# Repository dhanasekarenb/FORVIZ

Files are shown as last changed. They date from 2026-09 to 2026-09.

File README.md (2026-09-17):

# FORVIZ — face-tracking robot

FORVIZ is a stationary Raspberry Pi robot with a pan/tilt head, a camera, and one or two animated OLED displays. YuNet detects faces, the controller follows the largest face, and the eyes become happy after it stays centered for one second.

The V3 enclosure is a modular design intended for **PLA printing with a 0.4 mm nozzle**, using removable printed retainers and mechanically captive stock servo horns. No glue or added assembly screws are intended. **V3 is an engineering prototype; physical fit and loaded operation have not yet been tested.** Print the fit coupons and follow the mechanical guide before printing and assembling everything.

- [V3 mechanical and printing guide](docs/MECHANICAL_V3.md)
- [V3 printable STL files](3d_models/v3/stl)
- [Interactive 3D preview](docs/robot_preview.html) — download/open locally; works offline
- [Runtime, calibration, and troubleshooting](docs/RUNTIME.md)

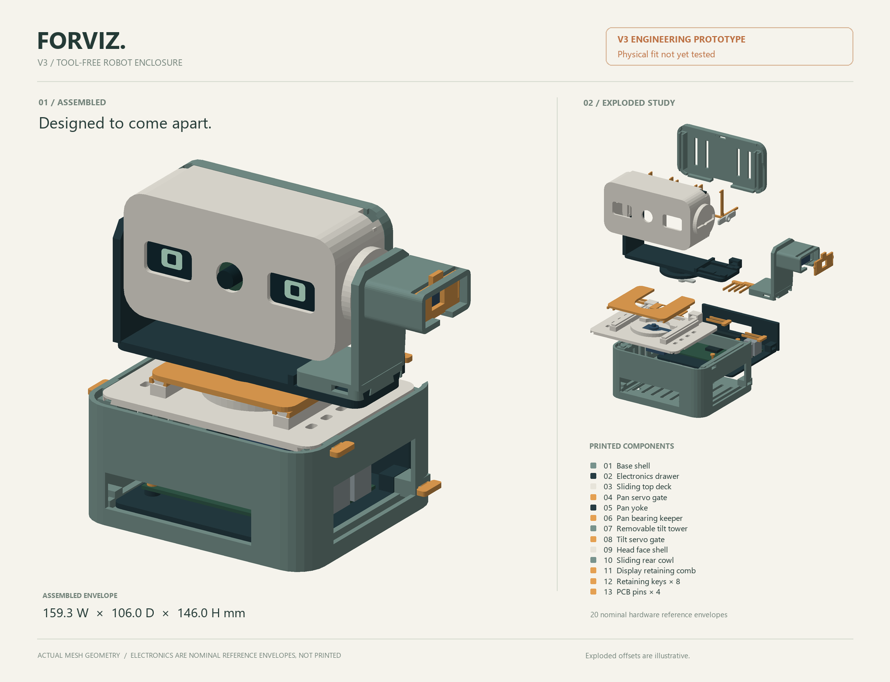
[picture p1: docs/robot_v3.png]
V3 engineering prototype: assembled and exploded printed components, physical fit not yet tested


## Hardware

| Component | Quantity | Purpose |
| --- | --- | --- |
| Raspberry Pi 4 Model B | 1 | Camera capture and face detection |
| Raspberry Pi Camera Rev 1.3 | 1 | CSI camera input |
| SG90 positional micro servo, with stock horn | 2 | Pan and tilt |
| 0.96-inch 128×64 SSD1306 I2C OLED | 2 for V3 | One eye per display; software also supports one display |
| Regulated external 5 V servo supply | 1 | Servo power, with ground shared with the Pi |
| Raspberry Pi power supply, wiring, and CSI ribbon | As needed | Controller power and interconnections |

Check your actual PCB, servo, and horn dimensions against the [mechanical guide](docs/MECHANICAL_V3.md). Modules sold under the same name can have different outlines. Use the specified stock horns in the printed captive mechanism; do not add horn-retaining screws or modify the servo internals.

## Wiring

Disconnect power before changing wiring. Power the servos from the external regulated 5 V supply and the Pi from its own suitable supply. Join the external supply ground to Pi ground; do not join the two supplies' positive outputs. Wire colors vary, so check the component labels.

| Connection | Destination |
| --- | --- |
| Pan servo signal | BCM GPIO 12, physical pin 32 |
| Tilt servo signal | BCM GPIO 19, physical pin 35 |
| Both servo positive leads | External regulated 5 V |
| Both servo grounds | External supply ground and Pi GND, e.g. physical pin 34 |
| Camera ribbon | Pi CSI camera connector |

For independent left/right eyes, use separate buses for two OLEDs with the same `0x3C` address:

| OLED connection | Left display / bus 1 | Right display / bus 3 |
| --- | --- | --- |
| VCC | 3.3 V, physical pin 1 | 3.3 V, physical pin 17 |
| GND | Physical pin 9 | Physical pin 25 |
| SDA | BCM GPIO 2, physical pin 3 | BCM GPIO 23, physical pin 16 |
| SCL | BCM GPIO 3, physical pin 5 | BCM GPIO 24, physical pin 18 |

The optional bus-3 setup below enables the second display. A display already configured for `0x3D` can instead share bus 1 with a `0x3C` display. The software probes supported addresses automatically. If both OLEDs share bus 1 and address `0x3C`, use `python3 test_oled.py --mirror-eye` and `python3 pi_tracker.py --mirror-eye`: both show the same centered eye. An I2C scan reports one address in that wiring and cannot count the physical screens.

## Set up the Raspberry Pi

Copy the complete project to the Pi and run these commands from its directory:

```bash
bash setup_pi.sh
```

The script installs system packages, enables I2C, attempts to start `pigpiod`, and downloads the YuNet model if it is missing. Check its output: some optional installation and service failures are reported without stopping the script. Keep `pi_tracker.py`, `servos.py`, and `oled_face.py` together. The main program imports the shared controllers.

For the second OLED on GPIO 23/24:

```bash
bash enable_dual_oled.sh
python3 test_oled.py --scan
```

Reboot if bus 3 is not available after enabling it. See [runtime setup troubleshooting](docs/RUNTIME.md#setup-and-dependencies) for dependency versions and `pigpiod` checks.

## Lower processing load and temperature

The tracker requests 320 × 240 capture at 15 FPS, limits detection to 15 runs per second, and uses one OpenCV worker thread. It also caps the inference image's longest side at 320 pixels if a camera returns larger frames. Face coordinates are mapped back to the original frame for tracking.

For the robot's same-bus mirrored OLEDs, run without the camera preview:

```bash
python3 pi_tracker.py --mirror-eye --headless
```

For a lower frame rate:

```bash
python3 pi_tracker.py --mirror-eye --headless --camera-fps 10 --detect-fps 10
```

Keep your existing rotation, servo direction, and calibration flags on these commands. The terminal reports available CPU temperature and firmware throttling flags every ten seconds. Reduced resolution can miss smaller or more distant faces; these defaults have not been thermally measured on your Pi. See [temperature checks and tuning](docs/RUNTIME.md#processing-load-and-temperature).

## Calibrate before tracking

1. **Simulate the servo sequence.** This runs without GPIO output or a camera:

   ```bash
   python3 test_servos.py --dry-run
   ```

2. **Center the unloaded servos before fitting the horns.** Support any attached head; this command holds both outputs at 90° until Ctrl+C:

   ```bash
   python3 test_servos.py --center-only
   ```

   Stop the command and disconnect servo power before fitting the stock horns and printed retainers. Preserve the neutral shaft orientation and follow the [V3 assembly guide](docs/MECHANICAL_V3.md). Stopping releases holding torque.

3. **Run the camera and servos manually with a narrow first sweep.** Keep the robot attended and check the ribbon, wires, joint clearance, and direction of movement:

   ```bash
   python3 pi_tracker.py --no-oled --headless \
     --pan-min 80 --pan-max 100 --tilt-min 80 --tilt-max 100 \
     --servo-speed 12 --scan-speed 6
   ```

   This command moves the real servos. Stop with Ctrl+C and support the head before power is removed. Increase the permitted range gradually only after verifying clearance. Software angle limits do not establish mechanical clearance or prevent a wrongly assembled joint from binding.

After the physical checks and OLED test, start normal operation:

```bash
python3 test_oled.py --dual
python3 pi_tracker.py
```

Default limits are **pan 40–140°** and **tilt 65–115°**, with both centers at 90°. Motion is limited to 36°/s; pan scanning uses 18°/s. These are conservative software starting values, not measured guarantees for your assembled print.

## Behavior

| State | Motion | Eyes |
| --- | --- | --- |
| `SCANNING` | Pan sweeps between configured limits; tilt eases toward its calibrated center | Neutral with scanning gaze |
| `TRACKING` | Pan and tilt move toward the largest detected face | Neutral, gaze follows the face |
| `LOCKED` | No movement inside the shared centering deadband | Happy after one continuous second centered |
| `HOLDING` | Holds position during a brief missed detection, for up to 1.5 seconds | Neutral with previous gaze |

The servos retain PWM while stationary by default so the head keeps holding torque. Optional `--idle-detach-after` releases that torque; it does not disconnect electrical power or guarantee a cool servo. Shutdown releases PWM without automatically moving the head back to center.

## Start automatically when the Pi boots

Run this once from the project directory on the Raspberry Pi:

```bash
bash robot_service.sh install
```

The installed `systemd` service starts `pi_tracker.py` in headless mirrored-eye mode after boot. It uses the current project directory, so later code changes take effect after restarting the service; the service does not copy the Python files.

When connecting a monitor to edit or test the code, stop the automatic instance first so two trackers do not compete for the camera and GPIO:

```bash
bash robot_service.sh stop
python3 pi_tracker.py --mirror-eye --headless --gain-tilt 60
bash robot_service.sh start
```

Use `bash robot_service.sh restart` after saving changes, `bash robot_service.sh status` to inspect its state, and `bash robot_service.sh logs` to follow runtime output. Use `disable` to keep it off across reboots and `enable` to restore automatic startup.

Shut down Raspberry Pi OS with `sudo poweroff` before disconnecting its power. During an operating-system shutdown, the service sends the tracker an interrupt so it releases servo PWM and closes the camera and OLED devices. Cutting electrical power cannot run that cleanup and may corrupt the microSD card.

This is face detection and tracking. The heart expression in the OLED demonstration is a manually selected animation, with no identity recognition attached to it.

## Useful commands

| Task | Command |
| --- | --- |
| Camera and simulated servo telemetry, no OLED output | `python3 pi_tracker.py --no-servo --no-oled` |
| One detected OLED displaying both eyes | `python3 pi_tracker.py --single-oled` |
| Use the installed upside-down OLEDs (default) | `python3 pi_tracker.py` |
| Override both displays to upright mounting | `python3 pi_tracker.py --oled-rotate 0` |
| Rotate Screen 1 and Screen 2 independently | `python3 pi_tracker.py --oled1-rotate 180 --oled2-rotate 0` |
| Keep the moving pupils in nightmare eyes | `python3 pi_tracker.py --mirror-eye --nightmare` |
| Keep the moving pupils in Naruto Sage-style eyes | `python3 pi_tracker.py --mirror-eye --naruto` |
| Keep the moving pupils in Uchiha three-tomoe eyes | `python3 pi_tracker.py --mirror-eye --uchiha` |
| Force a desktop camera preview | `python3 pi_tracker.py --preview` |
| Headless operation | `python3 pi_tracker.py --headless` |
| All runtime options | `python3 pi_tracker.py --help` |
| Hardware-free regression tests | `python3 -m unittest discover -s tests -v` |
| Rebuild the offline 3D viewer and PNG after a geometry export | `python3 tools/build_robot_preview.py` |

`--no-servo` disables physical servo output but continues calculating angles for telemetry. It still opens the camera. `--no-oled` only disables display output. The [runtime guide](docs/RUNTIME.md) describes all calibration flags, the PC vision demo, and validation limits.

## Source layout

| Path | Role |
| --- | --- |
| `pi_tracker.py` | Camera, YuNet detector, tracking state, CLI, and runtime cleanup |
| `servos.py` | Shared pan/tilt controller with elapsed-time motion |
| `oled_face.py` | Shared eye renderer and asynchronous OLED driver |
| `test_servos.py`, `test_oled.py` | Manual hardware demonstrations |
| `test_vision.py`, `run_pc_test.bat` | PC webcam vision demonstration |
| `tests/test_runtime.py` | Automated regressions with simulated hardware |
| `3d_models/v3/` | V3 source, exported assembly, and printable parts |
| `docs/` | Mechanical guide, runtime guide, and generated preview |

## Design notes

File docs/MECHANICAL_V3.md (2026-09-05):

# FORVIZ V3 FIELD — print and assembly guide

V3 is a removable PLA enclosure for the Raspberry Pi 4, two SG90 positional servos, two 0.96-inch SSD1306 OLED boards, and Pi Camera Rev 1.3, powered externally. The robot assembles with printed slides, gates, keys, and split pins: **no added screws, horn screws, glue, or heat-set inserts**. Leave the factory-assembled servos intact.

This is an engineering prototype with checked digital geometry. Print the fit gauges first; physical fit, loaded motion, and repeated removal still require validation on your printer and components.

## Files and dimensions

Open the [interactive assembly and exploded preview](robot_preview.html), [render](robot_v3.png), or [assembled GLB](../3d_models/v3/FORVIZ_V3_assembly.glb). Print from the [V3 STL folder](../3d_models/v3/stl). The [Python CAD source](../generate_3d_models_v3.py), [fit profile](../cad/v3_fit.json), [generated OpenSCAD](../3d_models/v3/FORVIZ_V3.scad), and [validation report](../3d_models/v3/validation.json) accompany the model. Wiring, centering commands, and first motion tests are in the [runtime guide](RUNTIME.md).

| Feature | Nominal dimension / setting |
| --- | --- |
| Complete neutral assembly, including keys | 159.3 W × 106 D × 146 H mm |
| Base shell | 120 × 106 × 56 mm |
| Head shell and cowl | 110 × 46 × 58 mm |
| Tilt axis above base underside | 117 mm |
| Shell wall | 2.4 mm |
| General mating clearance | 0.35 mm per side |
| Designed motion around neutral | Pan ±50°; tilt ±25° |
| Printing target | PLA; 0.4 mm nozzle |

Front means the camera/eye side: negative Y in the CAD. Rear is positive Y, right is positive X, and up is positive Z. The wider right side houses the removable tilt-servo tower. The external power arrangement has no internal battery compartment.

The V3 folder is the current print set. Earlier generators, `robot_body.scad`, and STL files outside `3d_models/v3` are legacy designs; their parts and assembly instructions do not belong to V3.

## What to print

There are **13 production designs, 23 production pieces, and eight fit-gauge designs**. The full export contains **21 unique STL files**. Gauges are separate from the 23 pieces used in the robot.

| STL prefix | Production part | Quantity |
| --- | --- | ---: |
| 01 | Base shell | 1 |
| 02 | Electronics drawer | 1 |
| 03 | Sliding top deck | 1 |
| 04 | Pan servo gate | 1 |
| 05 | Pan yoke with left pivot | 1 |
| 06 | Pan bearing keeper | 1 |
| 07 | Removable tilt tower | 1 |
| 08 | Tilt servo gate | 1 |
| 09 | Head face shell | 1 |
| 10 | Sliding rear cowl | 1 |
| 11 | Display retaining comb | 1 |
| 12 | Pull-release key | 8 |
| 13 | PCB snap pin | 4 |

The eight keys retain the drawer, deck, and pan keeper with two keys each, plus one key for the tilt tower and one for the cowl. All are the same printable design.

Start with 0.20 mm layers, four perimeters, and approximately 20–30% infill for large parts, then inspect the slicer preview. Print keys, pins, and their gauges solid. Use your filament's calibrated PLA temperature profile. PLA is comparatively brittle and heat-sensitive; keep cooling openings clear and avoid warm storage locations. See [Prusa's PLA material guidance](https://help.prusa3d.com/article/pla_2062).

STLs are already rotated for printing and placed on Z=0. Base, drawer, and deck print underside down; the yoke and tower print on a cheek; the head prints face down; the cowl prints rear face down. Keys lie flat, and split pins lie on their side. Preserve these orientations when evaluating the gauges.

Use localized supports where required under rail roofs, journal bosses, and servo-cradle overhangs. Keep support scars and seams away from sliding faces, horn pockets, bearing surfaces, and flexure roots. Remove supports fully before fitting electronics. Per-part rotations, sizes, and support notes are recorded in [validation.json](../3d_models/v3/validation.json).

The CAD's solid-volume PLA estimates are approximately 90.4 g for the complete printed head assembly and 354.5 g for all production pieces. These assume solid plastic throughout; use the slicer's result for actual filament and print-time estimates.

## Fit gauges before the robot

| Gauge | What to check |
| --- | --- |
| `fit_01_key_receivers` + `fit_02_key` | One/two/three dimples identify 0.20/0.35/0.50 mm clearance per side. Check sliding fit and gentle beam deflection. |
| `fit_03_stock_horn_pocket` | Check both actual double-arm horns, including hub and arm shape. |
| `fit_04_journal_ring` + `fit_05_journal_plug` | Check smooth rotation and removal without forcing or excessive rocking. |
| `fit_06_servo_body_gauge` | Check both servo cases; this shallow gauge does not verify the full ear or axial stack. |
| `fit_07_pcb_pin_seat` + `fit_08_dummy_pcb` | Stack the dummy PCB above the seat for a 6.6 mm capture thickness; test a production pin before fitting the Pi. |

The straight key-gauge channels lack the installed receivers' detent pockets. They test clearance and beam flex, **not final click or release effort**. Validate one actual keyed joint before printing all eight keys. Installed key channels are 8.6 × 3.1 mm: 0.30 mm clearance per side across the 8 mm shank and 0.35 mm per side across its 2.4 mm thickness. The middle gauge is 8.7 × 3.1 mm, so it is slightly wider.

A fitted key should enter with light finger pressure, settle into its detent, and withdraw by pulling its broad handle. Its beams should relax when seated. Remove a joint by its intended release direction rather than bending the enclosure. Replace a cracked or permanently bent key. Rounded roots, favorable layer orientation, and relaxed assembled flexures follow [Protolabs' snap-fit guidance](https://www.hubs.com/knowledge-base/how-design-snap-fit-joints-3d-printing/); the actual print determines usable force and service life.

## Component fit and regeneration

The nominal fit profile assumes 27.5 × 27.5 mm OLED PCBs, 26.7 × 19.3 × 2.3 mm OLED glass, a 25 × 24 mm camera PCB, and 1.6 mm PCB thickness. The larger glass envelope differs from the visible display window. Front lands contact PCB corners; the comb retains the backs and top corners while leaving central OLED headers clear.

Dry-fit both OLEDs and the camera before closing the head. Boards must rest flat on their intended lands, with no pressure on glass, chips, lens, or connectors. Confirm the active displays and camera lens align with their apertures. Board dimensions alone do not establish the optical offsets. Raspberry Pi publishes the Camera Module 1's approximate 25 × 24 × 9 mm overall envelope in its [camera specifications](https://www.raspberrypi.com/documentation/accessories/camera.html).

Pi supports use its four mounting holes, spaced 58 × 49 mm; the hole pattern is offset along the 85 mm board dimension. Use the orientation in the preview, with USB/Ethernet toward the right opening. See the [official Pi 4 mechanical drawing](https://datasheets.raspberrypi.com/rpi4/raspberry-pi-4-mechanical-drawing.pdf).

The model assumes two supplied **double-arm stock horns, 32 × 6 × 2 mm with an 8 mm hub**. The case envelope uses 23.2 × 12.6 mm, 32.5 mm ear length, and a 5.7 mm shaft offset. These are design assumptions to compare with your parts, not universal SG90 dimensions. [Tower Pro's SG90 specification](https://towerpro.com.tw/product/sg90-7/) identifies the manufacturer's servo; other suppliers and supplied horns can differ.

The pan journal and keeper carry axial/radial restraint around the stock horn. The left pivot, head cheeks, and locked right tower restrain the tilt horn. Both retain the original spline engagement without a horn screw. Confirm each horn remains engaged throughout the available axial play; a dimensionally clear pocket does not establish spline grip or load capacity.

Edit [cad/v3_fit.json](../cad/v3_fit.json) for supported OLED board/glass sizes, camera board/aperture sizes, optical offsets, horn sizes, horn height, and general clearance. Offsets are in millimetres; positive camera X moves right and positive optical Z moves up. `--clearance` overrides the profile's general clearance, within 0.15–0.65 mm per side. **Fixed key channels and pin holes are unaffected.** Structural dimensions and servo-body assumptions require editing the Python source and rechecking geometry.

From the project directory, install the separate [CAD dependencies](../requirements-cad.txt) and regenerate:

```bash
python -m pip install -r requirements-cad.txt
python generate_3d_models_v3.py --config cad/v3_fit.json --coupons-only --output 3d_models/v3_fit_trial
python generate_3d_models_v3.py --config cad/v3_fit.json
```

For a separate clearance trial, retain the component profile and choose a new output folder:

```bash
python generate_3d_models_v3.py --config cad/v3_fit.json --clearance 0.40 --output 3d_models/v3_trial
```

Use `python3` if that is your interpreter command. CAD dependencies are unnecessary to run the robot. Keep each generated fit set together, do not scale parts in the slicer, and inspect its validation report before printing. Regeneration updates STL/GLB/SCAD and mesh data; rebuild any separately generated preview after changing dimensions.

## Assembly order

1. Complete the gauge checks and remove all supports. Identify the front/rear directions in the preview. Keep power disconnected while fitting parts.
2. Center both unloaded servos with `python3 test_servos.py --center-only`, following the [runtime calibration instructions](RUNTIME.md#first-physical-calibration). Stop the command and disconnect power. Preserve the shaft positions while assembling; do not force the gear train around by hand.
3. Drop the Pi onto the drawer's four seats in the preview's orientation. Press four pins through the Pi mounting holes until their split ends retain below the drawer. Preconnect internal leads as needed, then slide the drawer into the base **from the rear** and insert its two side keys. Leave external power disconnected.
4. Thread loose head leads through the deck's rear cable opening. Slide the **bare deck from the rear** into the base and install its two side keys. The pan servo must be absent during this slide because its body would encounter the rear wall.
5. Lower the pan servo into the deck opening, with its offset output shaft centered on the bearing. Seat the mounting ears, then lower the thin pan gate over the case and ears. Fit one centered stock horn into the yoke's underside pocket and lower the yoke onto the servo spline and journal.
6. Slide the U-shaped bearing keeper **from the front**, below the yoke bridge, until seated. Insert its two keys **from the rear**. Confirm the keeper retains the flange while the journal can rotate without binding.
7. With the right tower detached, insert its centered tilt servo from the outboard end toward the inner cheek. Slide the tilt servo gate down into its tracks until the side detents engage. Fit the second stock horn into the empty head shell's right cheek pocket.
8. Support the empty head and place its left bearing over the yoke's fixed left pivot. Slide the complete right tower inward **from the right** on its dovetails, aligning the servo spline with the head's horn. Seat the tower against its stop and insert its rear key. Re-index the stock horn if neutral alignment is wrong; do not force engagement by twisting the head.
9. Fit the OLED and camera boards into their pockets **from the rear**, with displays/lens facing forward. Connect the leads with power disconnected. Insert the comb from the rear so its fingers retain board backs and its small caps sit above board top corners. Keep headers and camera connectors clear.
10. Route a relaxed cable loop through the head underside and behind the pan bearing. Keep the ribbon away from shaft pockets, sliding tracks, and closing edges. Slide the rear cowl **downward from above** onto its guides and insert its key from the rear.
11. Inspect the complete cable route and all retainers, then perform the narrow-range powered checks in the runtime guide. Expand toward pan ±50° and tilt ±25° only after the assembled robot moves freely with its actual wiring and load.

Use the external-power wiring described in [README](../README.md#wiring) and the runtime guide. Cable slack must accommodate both axes without tension at the CSI connectors. The CAD does not model a moving ribbon or wire bundle.

For service, disconnect power and support the head before releasing a structural key. Pull keys by their handles; slide the cowl up, tower right, keeper forward, and drawer rearward. Release Pi pins by squeezing their split ends **from below the withdrawn drawer** and lifting the heads; do not pry against the PCB. Remove the pan assembly and servo before sliding the top deck out. Reverse the assembly order for deeper disassembly.

## What has been verified

The shipped [validation report](../3d_models/v3/validation.json) records 21 watertight, consistently wound, positive-volume STL designs, each containing one connected solid. It reports zero printed-part overlaps in the assembled pose, including all eight keys and four pins; 100 sampled motion/insertion checks pass; and the nominal purchased-component envelopes have zero overlap with the assembled printed parts.

Those component envelopes are simplified reference geometry, not manufacturer CAD. The checks sample rigid poses rather than every point along continuous motion, and do not establish compatibility with every servo/OLED variant, cable motion, spline retention strength, thermal behavior, fatigue, or loaded physical operation. Fit gauges and the first slow assembled run remain part of completing this prototype.

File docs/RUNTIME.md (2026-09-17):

# FORVIZ runtime and calibration

The robot uses YuNet face detection, two bounded positional servos, and one or two SSD1306 OLEDs. The main program imports the shared controllers in `servos.py` and `oled_face.py`; transfer those files together.

For printing, stock-horn capture, wiring clearances, and removable joints, use the [V3 mechanical guide](MECHANICAL_V3.md). The [print files](../3d_models/v3/stl) and [offline 3D preview](robot_preview.html) describe the enclosure. V3 is an engineering prototype intended for PLA and a 0.4 mm nozzle; physical fit and loaded operation remain untested.

## Setup and dependencies

From the project directory on the Raspberry Pi:

```bash
bash setup_pi.sh
```

The script installs Raspberry Pi camera/GPIO packages, enables I2C, attempts to start `pigpiod`, and downloads `face_detection_yunet_2023mar.onnx` if needed. Some optional operations tolerate failure, so read the command output rather than relying solely on the final message.

The Python requirements include OpenCV 4.8 or newer, NumPy, Pillow, `luma.oled`, `gpiozero`, and `pigpio`. Picamera2 is supplied by Raspberry Pi OS. Check the OpenCV version in the interpreter that will run the robot:

```bash
python3 -c "import cv2; print(cv2.__version__)"
```

If distribution packages do not satisfy [requirements.txt](../requirements.txt), install those requirements in an environment that can still access the system Picamera2 package:

```bash
sudo apt install -y python3-venv
python3 -m venv --system-site-packages .venv
. .venv/bin/activate
python3 -m pip install -r requirements.txt
```

Activate that environment again in each new terminal before running the robot. Do not install both OpenCV's desktop and headless distributions into the same environment; `--headless` is a runtime option and does not require replacing OpenCV.

For the second OLED wired to GPIO 23/24:

```bash
bash enable_dual_oled.sh
python3 test_oled.py --scan
```

The script configures software I2C bus 3. Reboot if the new bus does not appear. The [README wiring tables](../README.md#wiring) list signal pins, OLED power, and the external servo supply. The external supply and Pi share ground; servo power is separate from the Pi's positive supply output.

## Processing load and temperature

Run the same-bus eye setup without preview processing:

```bash
python3 pi_tracker.py --mirror-eye --headless
```

The new defaults request **320 × 240 at 15 FPS**, with a maximum of **15 detection/servo updates per second** and **one OpenCV worker thread**. Previously capture requested 640 × 480 at 30 FPS and detection ran without an application rate limit; the Picamera2 branch did not apply the FPS setting to its camera configuration. The new Picamera2 configuration sets `FrameDurationLimits` and requests fresh frames with `queue=False`, as described in the [Picamera2 manual](https://datasheets.raspberrypi.com/camera/picamera2-manual.pdf).

Each detection uses at most a 320-pixel longest side by default, even if an OpenCV camera ignores the capture-size request. This gives 320 × 240 for a 4:3 frame: 75% fewer input pixels than 640 × 480. Resizing preserves the aspect ratio, and boxes/landmarks are mapped back to the captured frame. The input size is only reset when it changes. The loop sleeps between starts, with no bursts to catch up after a slow frame. These changes reduce work; the actual reduction in temperature depends on the Pi, ambient temperature, and enclosure airflow.

| Option | Default | Effect |
| --- | --- | --- |
| `--camera-width` / `--camera-height` | `320` / `240` | Requested capture dimensions; camera support varies |
| `--camera-fps` | `15` | Requested capture rate |
| `--detect-fps` | `15` | Caps detection and servo update rate, also limited by requested camera FPS |
| `--detect-size` | `320` | Maximum longest side of the inference image; smaller frames are not enlarged |
| `--cv-threads` | `1` | OpenCV worker thread setting |

For less processing, try `--camera-fps 10 --detect-fps 10` on the command above. Keep existing OLED rotation, servo direction, and calibrated limit flags. Smaller input can miss small/distant faces, and lower rates reduce responsiveness. Below 10 FPS the servo's existing 100 ms elapsed-time cap can also slow movement. For more face detail, try `--camera-width 640 --camera-height 480 --detect-size 480` while retaining the FPS cap; this increases processing cost. OLED animation stays on its existing separate worker.

The program prints available `[THERMAL]` readings every ten seconds in both headless and preview modes. It reads the Linux temperature sensor and, when installed, `vcgencmd get_throttled` with a bounded timeout. Current flags and flags from earlier in this boot are labelled separately. Missing readings do not stop tracking. A 75°C application warning asks you to check cooling; it does not change firmware settings, stop the robot, or guarantee an upper temperature limit.

Measure the Pi directly before and after several minutes with the same workload:

```bash
vcgencmd measure_temp
vcgencmd get_throttled
```

Raspberry Pi documents progressive Arm throttling between 80°C and 85°C; at 85°C the GPU is also throttled. Keep the enclosure vents clear and provide cooling if needed. Software optimization alone does not establish adequate cooling. See [official thermal management](https://www.raspberrypi.com/documentation/computers/raspberry-pi.html#frequency-management-and-thermal-control) and [firmware flag meanings](https://www.raspberrypi.com/documentation/computers/os.html#get_throttled).

## First physical calibration

The commanded angles are controller estimates, not measured shaft positions. SG90 variants, stock horns, printed fits, and ribbon routing must be checked on the actual build. The enclosure uses captive stock horns and printed retainers; follow the mechanical guide without adding horn screws or altering the servo internals.

1. Run the software sequence without GPIO or camera access:

   ```bash
   python3 test_servos.py --dry-run
   ```

   This takes approximately 12 seconds and exercises the manual demo in simulation. It does not establish physical clearance.

2. With unloaded servos wired to the external supply, command neutral:

   ```bash
   python3 test_servos.py --center-only
   ```

   Both outputs hold at 90° until Ctrl+C. Stop, disconnect servo power, and fit the stock horns in the neutral orientation described in the mechanical guide. Preserve the shaft position during assembly. Support any attached head before stopping or disconnecting power, because PWM release removes holding torque.

3. Start the camera and real servos manually, initially using a small motion envelope:

   ```bash
   python3 pi_tracker.py --no-oled --headless \
     --pan-min 80 --pan-max 100 --tilt-min 80 --tilt-max 100 \
     --servo-speed 12 --scan-speed 6
   ```

   Startup commands the configured center. With no face visible, the head begins scanning. Watch cable slack, clearance, horn retention, motion direction, and load throughout this first run. Stop with Ctrl+C before correcting anything. The tracker should reduce the face's offset; if it moves away from the face or binds, correct the assembly/wiring before expanding travel.

4. Expand the limits gradually after checking the complete intended movement. Default bounds are pan 40–140° and tilt 65–115°. Keep narrower values if your assembled robot needs them. These defaults have not been physically verified on your print.

5. Test the OLEDs, then run the complete robot:

   ```bash
   python3 test_oled.py --dual
   python3 pi_tracker.py
   ```

The optional `python3 test_servos.py` command runs a physical 12-second sine-motion demonstration covering pan 55–125° and tilt 70–110°. Use it only after that motion range has been checked. It reports command completion, not a sensor-confirmed test result.

## Runtime options

```bash
python3 pi_tracker.py --help
```

| Option | Default | Effect |
| --- | --- | --- |
| `--no-servo` | Off | Simulates commanded pan/tilt angles; sends no physical servo output |
| `--no-oled` | Off | Disables physical OLED output |
| `--headless` | Automatic on systems without a detected GUI/display | Disables the camera preview and prints telemetry |
| `--preview` | Off | Requests the OpenCV desktop preview |
| `--single-oled` | Off | Uses one detected OLED with both eyes on it |
| `--dual-oled` | Off | Requests two OLEDs, falling back to available displays |
| `--oled-rotate` | `180` | Rotates both OLEDs to match their upside-down physical mounting (`0`, `90`, `180`, `270` deg) |
| `--oled1-rotate` | None | Rotates Screen 1 specifically (`0`, `90`, `180`, `270` deg) |
| `--oled2-rotate` | None | Rotates Screen 2 specifically (`0`, `90`, `180`, `270` deg) |
| `--pan-pin`, `--tilt-pin` | `12`, `19` | BCM GPIO signal pins; must be distinct |
| `--pan-min`, `--pan-max` | `40`, `140` | Pan limits in commanded degrees |
| `--tilt-min`, `--tilt-max` | `65`, `115` | Tilt limits in commanded degrees |
| `--pan-center`, `--tilt-center` | `90`, `90` | Startup center; scan also returns tilt to its center |
| `--servo-speed` | `36` | Maximum tracking/tilt-return speed in degrees per second |
| `--scan-speed` | `18` | Pan scan speed in degrees per second, capped by servo speed |
| `--face-loss-sec` | `1.5` | Time to hold position after the last face detection before scanning |
| `--idle-detach-after` | Disabled | Optional idle timeout in seconds that releases PWM and holding torque |
| `--model` | YuNet ONNX file beside `pi_tracker.py` | Overrides the detector model path |

`--headless` and `--preview` are mutually exclusive, as are `--single-oled` and `--dual-oled`. Centers must lie inside their configured ranges. Speeds must be positive. An explicitly supplied relative model path is resolved from the current working directory; the default model location is independent of that directory.

### Simulation still uses the camera

```bash
python3 pi_tracker.py --no-servo --no-oled --preview
```

This processes a real camera stream and calculates simulated angles for the overlay. It does not output servo PWM or OLED frames. To check software without opening a camera, use the regression suite or `test_servos.py --dry-run` instead.

`--no-oled` by itself leaves physical servo movement enabled. Read the startup backend message: `DUMMY`/simulation means no physical servo output, even if `--no-servo` was not supplied because no usable hardware backend was found.

## Tracking and eyes

`PiCameraStream` uses Picamera2 when available, with an OpenCV camera fallback. Picamera2's `RGB888` array uses BGR byte order for OpenCV, so the runtime passes it through directly; see the [Picamera2 manual](https://datasheets.raspberrypi.com/camera/picamera2-manual.pdf). YuNet chooses the largest detected face each frame; it does not identify a person or preserve a person's identity when multiple faces cross.

| State | Transition and behavior |
| --- | --- |
| `SCANNING` | Initial state with no detection, or after the face-loss timeout. Pan reverses at its configured limits and tilt moves smoothly toward the calibrated center. |
| `TRACKING` | The smoothed face center is outside the centering deadband. Each axis moves only when its own error exceeds the deadband. |
| `LOCKED` | Both normalized offsets are within ±0.08 of half the frame dimension. The eyes turn happy after one continuous second centered. |
| `HOLDING` | A previously visible face disappears for less than the configured timeout. The robot holds its last angles and displays neutral eyes. |

Face-position smoothing and servo movement use monotonic elapsed time. Each servo update accounts for at most 100 ms, limiting movement after an inference stall. A missed detection resets the happy-expression timer. A face reacquired before scanning resumes can continue from the previous smoothed position.

The eye controller probes bus 1 at the primary address and supported secondary addresses/buses. A display found only on a secondary bus becomes the primary screen. If one display fails during animation, the remaining display continues with both eyes on it. Failures are logged, and the animation thread owns display cleanup.

Manual display demos:

```bash
python3 test_oled.py --single
python3 test_oled.py --dual
```

The demo cycles through gaze directions, happy eyes, and heart eyes. Hearts are a demonstration expression, not a face-recognition result. SSD1306 output is monochrome.

## Holding torque and shutdown

Stationary servos keep PWM enabled by default. This lets the motor hold the head against gravity. The optional `--idle-detach-after` setting releases PWM after a stationary period; the head may then sag or fall. PWM release does not cut electrical supply power, eliminate all current, or guarantee safe temperatures.

Press Ctrl+C in any runtime mode, or Q/Escape in the desktop preview, to stop. Shutdown releases PWM at the current position, stops OLED animation, and releases the camera. It does not command an abrupt return to center. Support the head when releasing torque. Disconnect power before adjusting wiring or mechanical retention.

### Automatic startup and development

From the project directory on the Raspberry Pi, install the boot service once:

```bash
bash robot_service.sh install
```

The service runs the tracker with `--mirror-eye --headless --gain-tilt 60`. It points directly at this project directory. Stop it before opening the camera or GPIO from a manual test, then restart it after editing:

```bash
bash robot_service.sh stop
python3 pi_tracker.py --mirror-eye --headless --gain-tilt 60
bash robot_service.sh start
```

Other controls are `restart`, `status`, `logs`, `disable`, `enable`, and `remove`. A normal Raspberry Pi OS shutdown stops the service cleanly. Removing electrical power without `sudo poweroff` bypasses software cleanup and risks microSD corruption.

## Troubleshooting

| Symptom | Check |
| --- | --- |
| Model missing | Run `bash setup_pi.sh`; verify the ONNX file beside `pi_tracker.py`, or provide `--model`. |
| YuNet/OpenCV load error | Check the active interpreter, OpenCV version, model file, and requirements. Do not substitute a Git LFS pointer text file for the actual ONNX model. |
| Servo backend is simulation unexpectedly | Check GPIO packages and `systemctl status pigpiod`. On the supported Pi 4 setup, `sudo systemctl start pigpiod` starts the daemon when it is installed. |
| Servo hums, binds, or the Pi resets | Stop the run. Check physical clearance, load, external servo power, and shared ground before trying again. Detaching PWM is not a substitute for correcting binding. |
| Camera cannot open | Check the CSI ribbon with power disconnected, camera availability, and whether another process is using it. |
| Second OLED missing | For independent left/right eyes, check bus-3 wiring/overlay and `python3 test_oled.py --scan`; two `0x3C` displays cannot be addressed separately on the same bus. For identical mirrored eyes on both screens, use `--mirror-eye`; a scan sees one address even with two physical screens. |
| No preview | Use `--preview` on a graphical desktop; use `--headless` over a terminal-only connection. |

## PC demo and automated checks

The PC webcam demonstration uses the shared YuNet detector and displays tracking telemetry without servo control:

```bash
python test_vision.py
```

On Windows, `run_pc_test.bat` runs the same script using `python` from PATH and changes to the project directory first. Q/Escape quits, C toggles the overlay, S saves a snapshot, and M switches modes when optional YOLO support is installed. The optional object detector needs Ultralytics and its model weights; the main robot does not require it.

Run hardware-free regression checks from the project directory:

```bash
python3 -m unittest discover -s tests -v
```

The tests cover motion across frame rates, stalled-frame limits, scan transitions, centering/deadband behavior, lost-face timing, OLED discovery/disconnection, rendering, and cleanup after partial initialization. Hardware demos are excluded from pytest collection. These checks do not activate a camera or establish servo calibration, print fit, load capacity, temperature, or physical collision clearance.

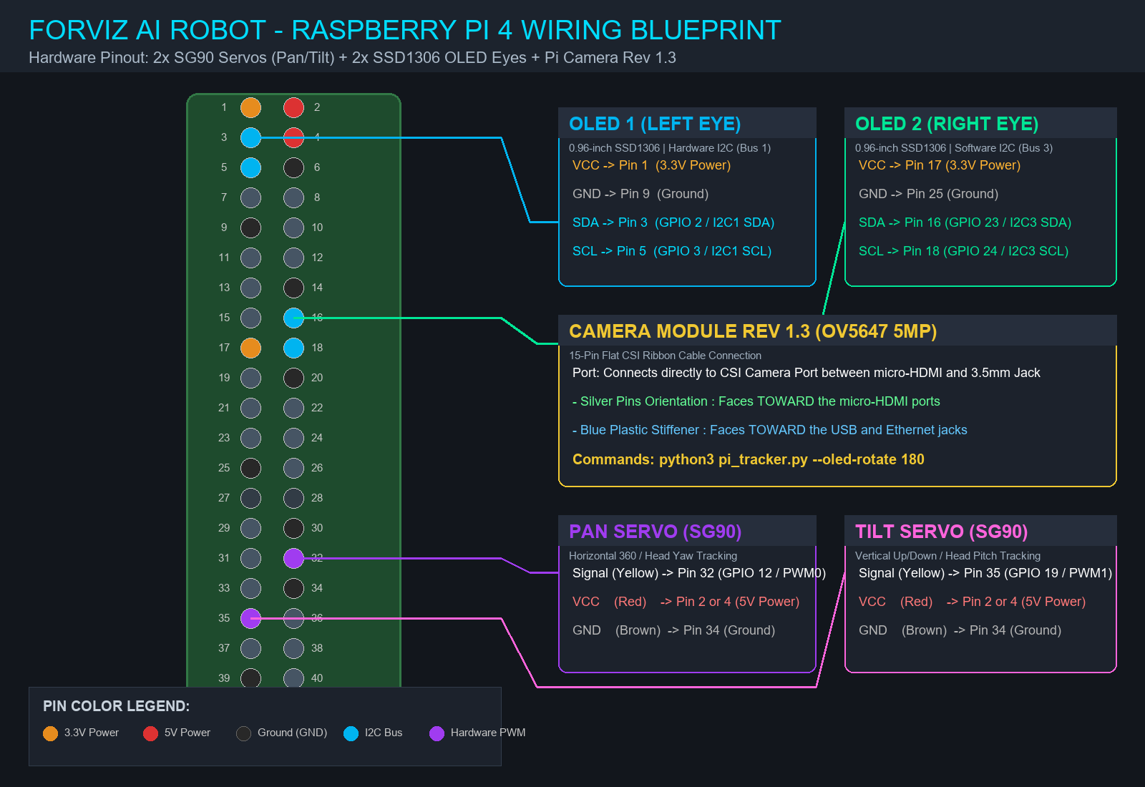
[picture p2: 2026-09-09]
docs/raspberry_pi4_pinout.png

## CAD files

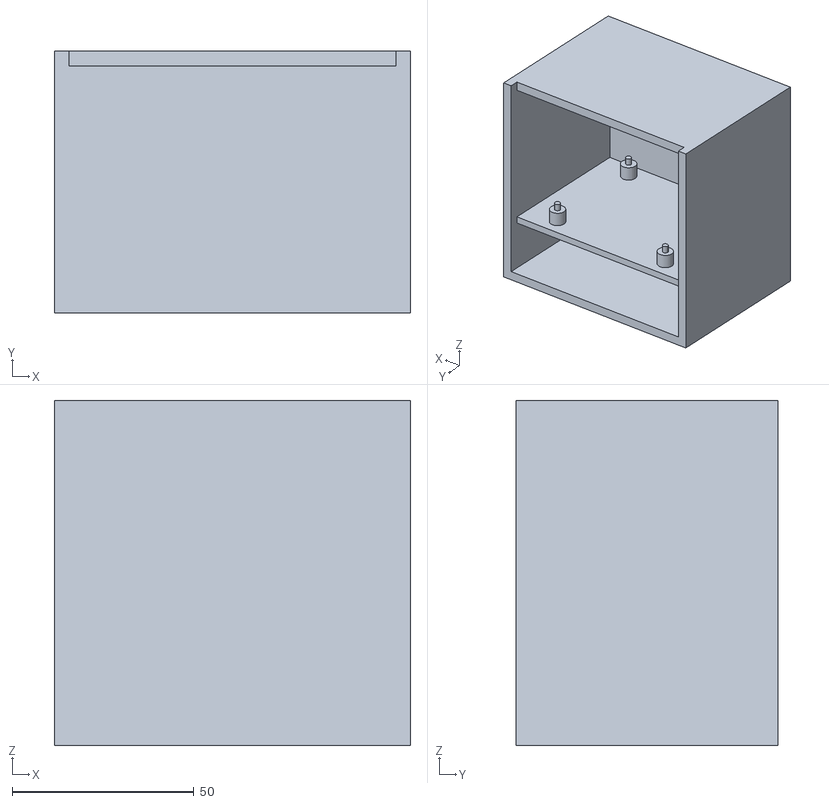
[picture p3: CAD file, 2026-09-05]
3d_models/robot_torso_chassis.stl
98.0 x 72.0 x 95.0

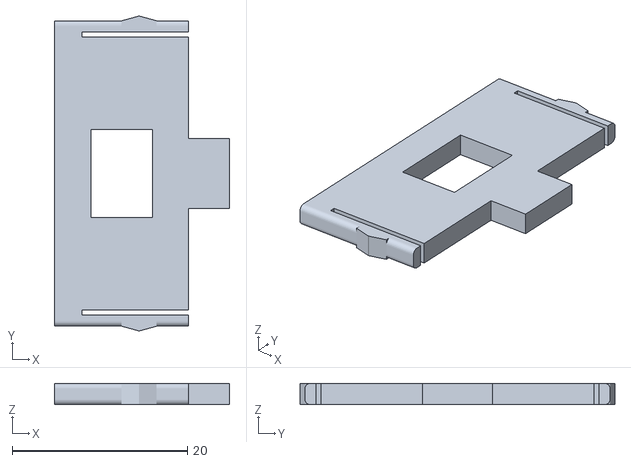
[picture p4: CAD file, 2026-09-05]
3d_models/v3/stl/08_tilt_servo_gate.stl
20.0 x 35.9 x 2.40

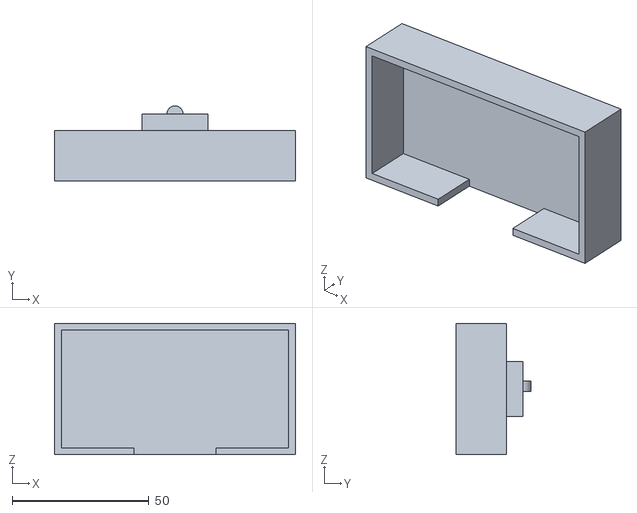
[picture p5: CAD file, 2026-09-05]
3d_models/head_rear_cowl.stl
88.0 x 27.5 x 48.0

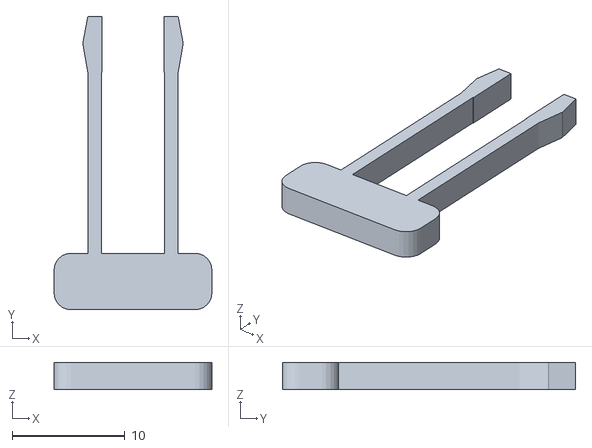
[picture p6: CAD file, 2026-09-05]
3d_models/v3/stl/fit_02_key.stl
14.0 x 26.0 x 2.40

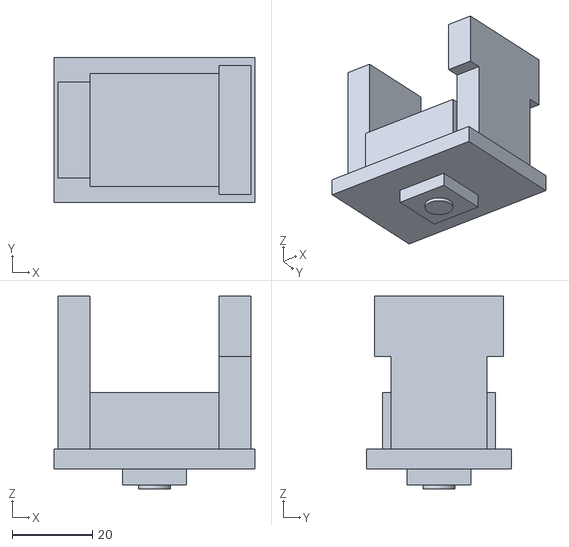
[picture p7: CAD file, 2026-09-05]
3d_models/pan_tilt_gimbal.stl
50.0 x 36.0 x 48.0

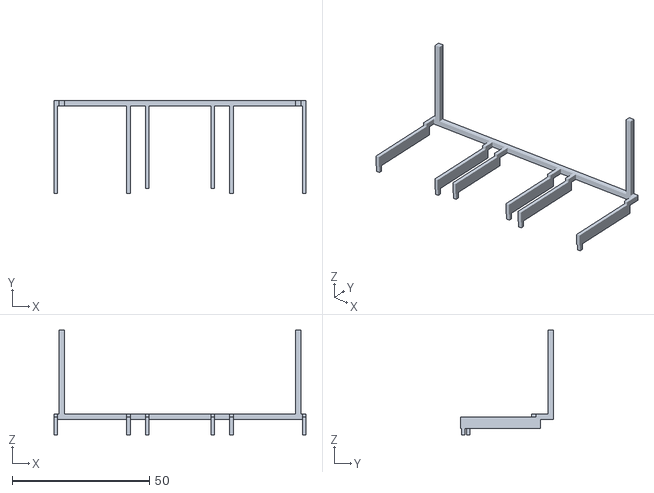
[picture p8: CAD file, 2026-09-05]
3d_models/v3/stl/11_display_retaining_comb.stl
91.8 x 33.8 x 38.1

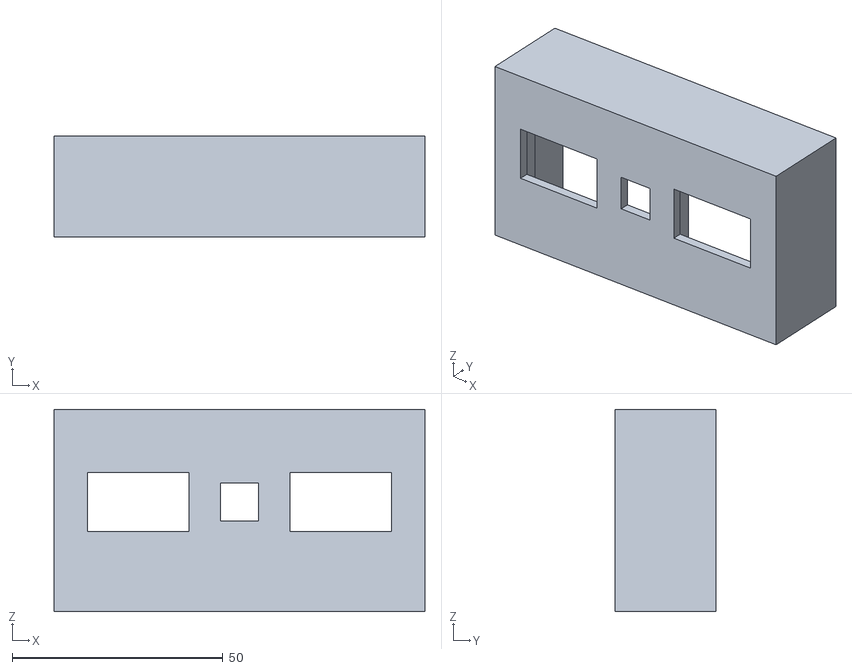
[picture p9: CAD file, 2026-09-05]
3d_models/head_front_faceplate.stl
88.0 x 24.0 x 48.0

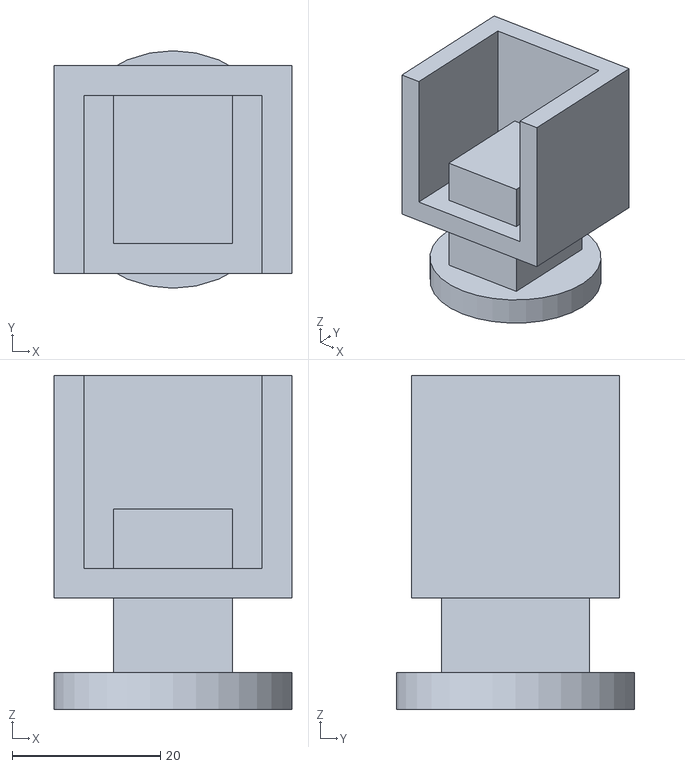
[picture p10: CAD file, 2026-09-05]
3d_models/neck_tilt_bracket.stl
32.0 x 32.0 x 45.0

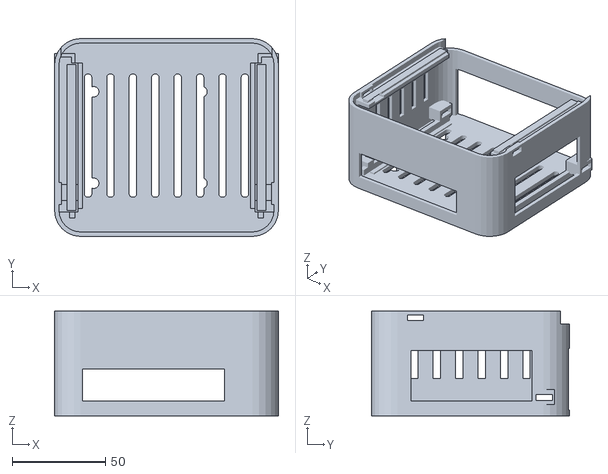
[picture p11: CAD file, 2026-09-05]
3d_models/v3/stl/01_base_shell.stl
120.0 x 106.0 x 56.0

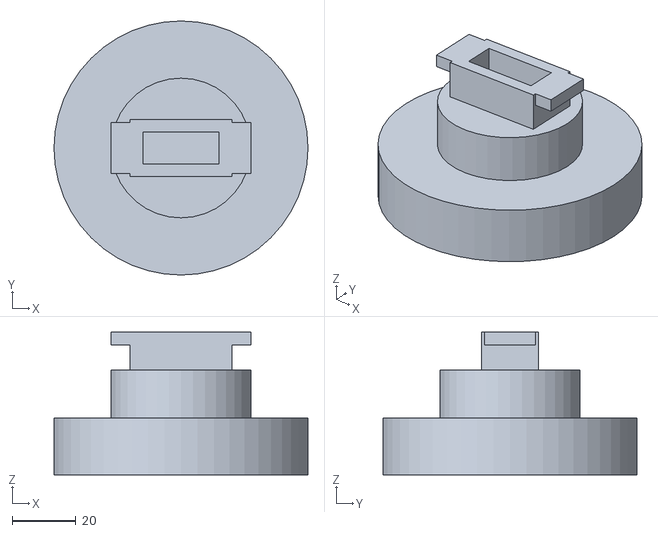
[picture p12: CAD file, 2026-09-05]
3d_models/robot_base_stand.stl
80.0 x 80.0 x 45.0

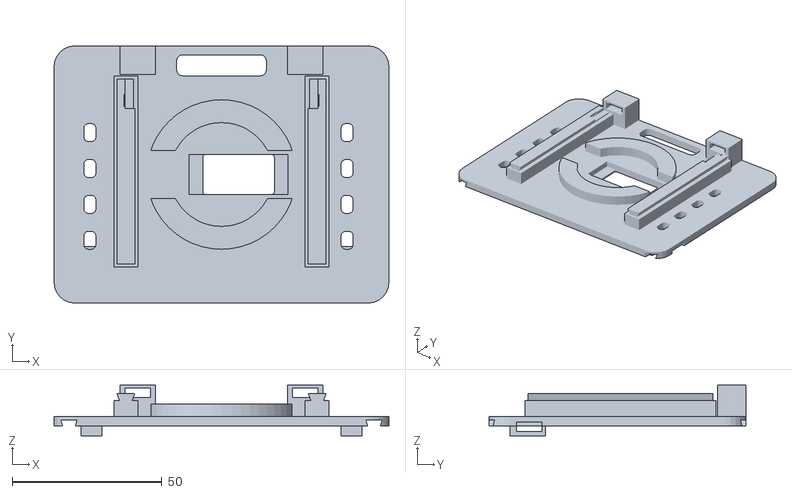
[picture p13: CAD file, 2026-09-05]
3d_models/v3/stl/03_sliding_top_deck.stl
112.0 x 86.0 x 16.9

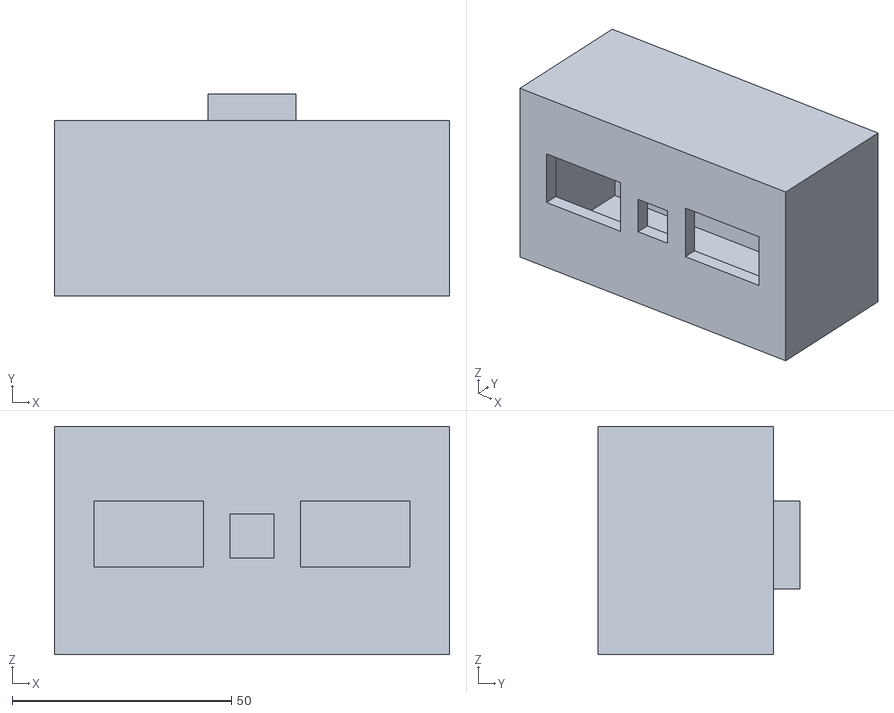
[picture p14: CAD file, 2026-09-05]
3d_models/robot_head_face.stl
90.0 x 46.0 x 52.0

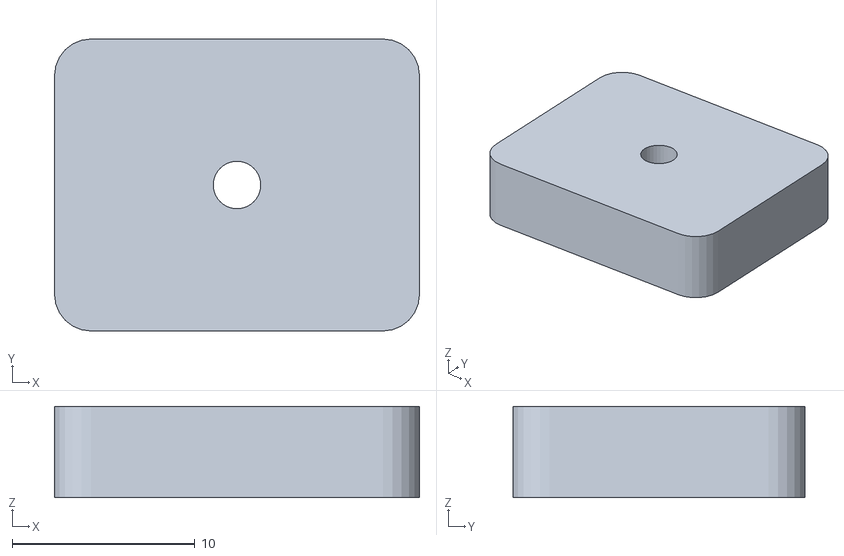
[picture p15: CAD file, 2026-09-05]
3d_models/v3/stl/fit_07_pcb_pin_seat.stl
20.0 x 16.0 x 5.00

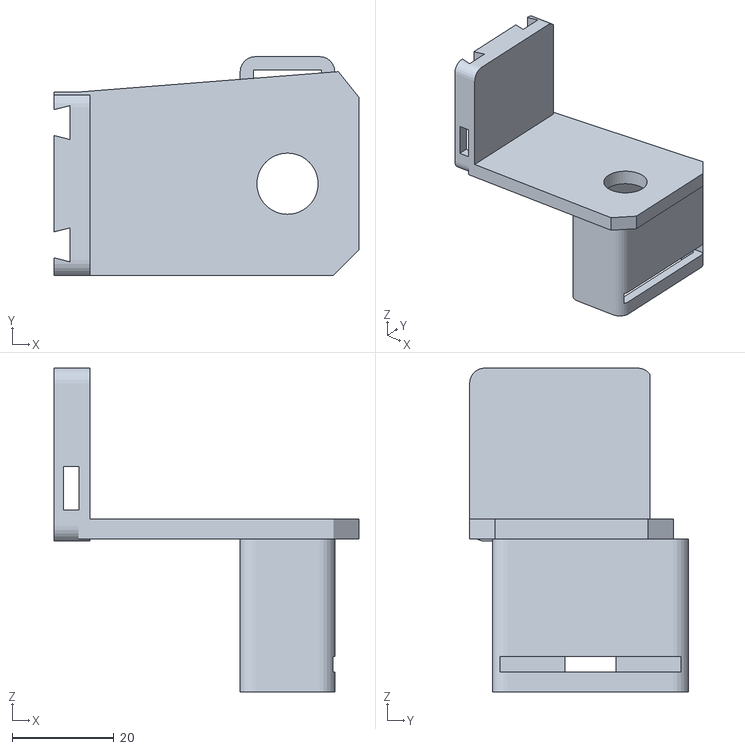
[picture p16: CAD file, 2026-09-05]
3d_models/v3/stl/07_removable_tilt_tower.stl
59.8 x 43.0 x 63.6

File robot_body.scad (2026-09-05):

// FORVIZ V3: current screwless robot assembly.
// Select part / exploded / show_references in the included file.
// Print individual oriented STLs in 3d_models/v3/stl.
// Edit cad/v3_fit.json or generate_3d_models_v3.py, then regenerate.
// Build instructions: docs/MECHANICAL_V3.md
include <3d_models/v3/FORVIZ_V3.scad>

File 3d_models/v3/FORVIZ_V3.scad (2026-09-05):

// Generated by generate_3d_models_v3.py. All units mm.
// Edit Dimensions or use --config and regenerate to change fits.
part = "assembly"; // or a module name listed below
exploded = 0; // 0 assembled, 1 exploded
show_references = true; // bought hardware, never printable

module p_01_base_shell(){difference(){difference(){difference(){difference(){difference(){difference(){difference(){difference(){difference(){difference(){difference(){difference(){difference(){union(){difference(){union(){union(){union(){union(){union(){union(){union(){union(){union(){difference(){union(){difference(){union(){union(){union(){union(){union(){union(){union(){union(){union(){difference(){difference(){difference(){difference(){difference(){difference(){difference(){difference(){difference(){difference(){difference(){difference(){difference(){difference(){difference(){difference(){difference(){hull(){union(){union(){union(){translate([-46.0, -39.0, 0.0]){cylinder(h=56.0,r1=14,r2=14,$fn=24);}translate([-46.0, 39.0, 0.0]){cylinder(h=56.0,r1=14,r2=14,$fn=24);}}translate([46.0, -39.0, 0.0]){cylinder(h=56.0,r1=14,r2=14,$fn=24);}}translate([46.0, 39.0, 0.0]){cylinder(h=56.0,r1=14,r2=14,$fn=24);}}}hull(){union(){union(){union(){translate([-46.0, -39.0, 3.0]){cylinder(h=57.0,r1=11.6,r2=11.6,$fn=24);}translate([-46.0, 39.0, 3.0]){cylinder(h=57.0,r1=11.6,r2=11.6,$fn=24);}}translate([46.0, -39.0, 3.0]){cylinder(h=57.0,r1=11.6,r2=11.6,$fn=24);}}translate([46.0, 39.0, 3.0]){cylinder(h=57.0,r1=11.6,r2=11.6,$fn=24);}}}}hull(){union(){union(){union(){translate([-48.0, 48.0, 3.0]){cylinder(h=33,r1=2,r2=2,$fn=24);}translate([-48.0, 56.0, 3.0]){cylinder(h=33,r1=2,r2=2,$fn=24);}}translate([48.0, 48.0, 3.0]){cylinder(h=33,r1=2,r2=2,$fn=24);}}translate([48.0, 56.0, 3.0]){cylinder(h=33,r1=2,r2=2,$fn=24);}}}}translate([-56.5, 39.0, 49.2]){cube([113,20,9]);}}translate([55.0, -32.0, 8.0]){cube([12,65,27]);}}translate([-45.0, -58.0, 8.0]){cube([76,12,17]);}}hull(){union(){union(){union(){translate([-42.2, -30.2, -1.0]){cylinder(h=5,r1=1.8,r2=1.8,$fn=24);}translate([-42.2, 32.2, -1.0]){cylinder(h=5,r1=1.8,r2=1.8,$fn=24);}}translate([-41.8, -30.2, -1.0]){cylinder(h=5,r1=1.8,r2=1.8,$fn=24);}}translate([-41.8, 32.2, -1.0]){cylinder(h=5,r1=1.8,r2=1.8,$fn=24);}}}}hull(){union(){union(){union(){translate([-30.2, -30.2, -1.0]){cylinder(h=5,r1=1.8,r2=1.8,$fn=24);}translate([-30.2, 32.2, -1.0]){cylinder(h=5,r1=1.8,r2=1.8,$fn=24);}}translate([-29.8, -30.2, -1.0]){cylinder(h=5,r1=1.8,r2=1.8,$fn=24);}}translate([-29.8, 32.2, -1.0]){cylinder(h=5,r1=1.8,r2=1.8,$fn=24);}}}}hull(){union(){union(){union(){translate([-18.2, -30.2, -1.0]){cylinder(h=5,r1=1.8,r2=1.8,$fn=24);}translate([-18.2, 32.2, -1.0]){cylinder(h=5,r1=1.8,r2=1.8,$fn=24);}}translate([-17.8, -30.2, -1.0]){cylinder(h=5,r1=1.8,r2=1.8,$fn=24);}}translate([-17.8, 32.2, -1.0]){cylinder(h=5,r1=1.8,r2=1.8,$fn=24);}}}}hull(){union(){union(){union(){translate([-6.2, -30.2, -1.0]){cylinder(h=5,r1=1.8,r2=1.8,$fn=24);}translate([-6.2, 32.2, -1.0]){cylinder(h=5,r1=1.8,r2=1.8,$fn=24);}}translate([-5.8, -30.2, -1.0]){cylinder(h=5,r1=1.8,r2=1.8,$fn=24);}}translate([-5.8, 32.2, -1.0]){cylinder(h=5,r1=1.8,r2=1.8,$fn=24);}}}}hull(){union(){union(){union(){translate([5.8, -30.2, -1.0]){cylinder(h=5,r1=1.8,r2=1.8,$fn=24);}translate([5.8, 32.2, -1.0]){cylinder(h=5,r1=1.8,r2=1.8,$fn=24);}}translate([6.2, -30.2, -1.0]){cylinder(h=5,r1=1.8,r2=1.8,$fn=24);}}translate([6.2, 32.2, -1.0]){cylinder(h=5,r1=1.8,r2=1.8,$fn=24);}}}}hull(){union(){union(){union(){translate([17.8, -30.2, -1.0]){cylinder(h=5,r1=1.8,r2=1.8,$fn=24);}translate([17.8, 32.2, -1.0]){cylinder(h=5,r1=1.8,r2=1.8,$fn=24);}}translate([18.2, -30.2, -1.0]){cylinder(h=5,r1=1.8,r2=1.8,$fn=24);}}translate([18.2, 32.2, -1.0]){cylinder(h=5,r1=1.8,r2=1.8,$fn=24);}}}}hull(){union(){union(){union(){translate([29.8, -30.2, -1.0]){cylinder(h=5,r1=1.8,r2=1.8,$fn=24);}translate([29.8, 32.2, -1.0]){cylinder(h=5,r1=1.8,r2=1.8,$fn=24);}}translate([30.2, -30.2, -1.0]){cylinder(h=5,r1=1.8,r2=1.8,$fn=24);}}translate([30.2, 32.2, -1.0]){cylinder(h=5,r1=1.8,r2=1.8,$fn=24);}}}}hull(){union(){union(){union(){translate([41.8, -30.2, -1.0]){cylinder(h=5,r1=1.8,r2=1.8,$fn=24);}translate([41.8, 32.2, -1.0]){cylinder(h=5,r1=1.8,r2=1.8,$fn=24);}}translate([42.2, -30.2, -1.0]){cylinder(h=5,r1=1.8,r2=1.8,$fn=24);}}translate([42.2, 32.2, -1.0]){cylinder(h=5,r1=1.8,r2=1.8,$fn=24);}}}}translate([-39.0, -24.5, -1.0]){cylinder(h=5,r1=2.8,r2=2.8,$fn=32);}}translate([-39.0, 24.5, -1.0]){cylinder(h=5,r1=2.8,r2=2.8,$fn=32);}}translate([19.0, -24.5, -1.0]){cylinder(h=5,r1=2.8,r2=2.8,$fn=32);}}translate([19.0, 24.5, -1.0]){cylinder(h=5,r1=2.8,r2=2.8,$fn=32);}}translate([-52.0, -43.0, 3.0]){cube([3,86,4]);}}translate([-48.0, -38.0, 2.9]){cube([3,78,1.1]);}}translate([-57.7, -40.0, 49.6]){cube([10.4,80,2.8]);}}translate([-51.0, 39.0, 52.0]){rotate([90.0, 0.0, 0.0]){linear_extrude(height=78) polygon([[-1.4, 0], [1.4, 0], [2.4, 2.5], [-2.4, 2.5]]);}}}translate([-58.0, -39.0, 3.0]){cube([9,6,7]);}}translate([-58.0, -39.0, 49.6]){cube([7,6,2.8]);}}translate([-58.0, 37.0, 3.0]){cube([9,6,7]);}}translate([-58.0, 37.0, 49.6]){cube([7,6,2.8]);}}translate([-60.0, 33.0, 6.0]){cube([11,12,8]);}}translate([-61.0, 35.2, 8.2]){cube([21,8.6,3.1]);}}translate([-60.0, -36.0, 48.4]){cube([3.65,12,7.6]);}}translate([-61.0, -33.8, 51.0]){cube([21,8.6,3.1]);}}translate([49.0, -43.0, 3.0]){cube([3,86,4]);}}translate([45.0, -38.0, 2.9]){cube([3,78,1.1]);}}translate([47.3, -40.0, 49.6]){cube([10.4,80,2.8]);}}translate([51.0, 39.0, 52.0]){rotate([90.0, 0.0, 0.0]){linear_extrude(height=78) polygon([[-1.4, 0], [1.4, 0], [2.4, 2.5], [-2.4, 2.5]]);}}}translate([49.0, -39.0, 3.0]){cube([9,6,7]);}}translate([51.0, -39.0, 49.6]){cube([7,6,2.8]);}}translate([49.0, 37.0, 3.0]){cube([9,6,7]);}}translate([51.0, 37.0, 49.6]){cube([7,6,2.8]);}}translate([49.0, 33.0, 6.0]){cube([11,12,8]);}}translate([40.0, 35.2, 8.2]){cube([21,8.6,3.1]);}}translate([56.35, -36.0, 48.4]){cube([3.65,12,7.6]);}}translate([40.0, -33.8, 51.0]){cube([21,8.6,3.1]);}}translate([-62.0, -32.0, 20.0]){cube([7,4,19]);}}translate([-62.0, -20.0, 20.0]){cube([7,4,19]);}}translate([-62.0, -8.0, 20.0]){cube([7,4,19]);}}translate([-62.0, 4.0, 20.0]){cube([7,4,19]);}}translate([-62.0, 16.0, 20.0]){cube([7,4,19]);}}translate([-62.0, 28.0, 20.0]){cube([7,4,19]);}}translate([-62.35, 39.5, 8.55]){rotate([0.0, 0.0, -90.0]){translate([-4.6, 18.6, -0.15]){cube([9.2,4.0,2.7]);}}}}translate([62.35, 39.5, 8.55]){rotate([0.0, 0.0, 90.0]){translate([-4.6, 18.6, -0.15]){cube([9.2,4.0,2.7]);}}}}translate([-62.35, -29.5, 51.35]){rotate([0.0, 0.0, -90.0]){translate([-4.6, 18.6, -0.15]){cube([9.2,4.0,2.7]);}}}}translate([62.35, -29.5, 51.35]){rotate([0.0, 0.0, 90.0]){translate([-4.6, 18.6, -0.15]){cube([9.2,4.0,2.7]);}}}}translate([-28.0, 45.35, 62.65]){rotate([0.0, 0.0, 180.0]){translate([-4.6, 18.6, -0.15]){cube([9.2,4.0,2.7]);}}}}translate([28.0, 45.35, 62.65]){rotate([0.0, 0.0, 180.0]){translate([-4.6, 18.6, -0.15]){cube([9.2,4.0,2.7]);}}}}}

if(part=="01_base_shell") p_01_base_shell();

if(part=="assembly") color("#78938d") translate(exploded*[0, 0, -25]) p_01_base_shell();
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

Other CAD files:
3d_models/v3/stl/fit_08_dummy_pcb.stl
3d_models/v3/stl/09_head_face_shell.stl
3d_models/v3/stl/06_pan_bearing_keeper.stl
cad/legacy_robot_body.scad
3d_models/v3/stl/02_electronics_drawer.stl
3d_models/v3/stl/04_pan_servo_gate.stl
3d_models/v3/stl/05_pan_yoke.stl
3d_models/v3/stl/10_sliding_rear_cowl.stl
3d_models/v3/stl/13_pcb_snap_pin.stl
3d_models/v3/stl/fit_01_key_receivers.stl
3d_models/v3/stl/fit_03_stock_horn_pocket.stl
3d_models/v3/stl/fit_04_journal_ring.stl
3d_models/v3/stl/fit_05_journal_plug.stl
3d_models/v3/stl/fit_06_servo_body_gauge.stl

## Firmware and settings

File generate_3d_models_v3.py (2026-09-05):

"""FORVIZ V3 / FIELD — serviceable, screwless robot CAD.

All dimensions are millimetres. X is right, Y is rear, Z is up. The source
uses real Manifold boolean solids, exports independent printable STL parts,
an assembled GLB, OpenSCAD source and an auditable dimensions/mesh report.
See docs/MECHANICAL_V3.md before printing: stock servo/horn dimensions vary.
"""
from __future__ import annotations

import argparse
from dataclasses import asdict, dataclass, replace
import hashlib
import json
import math
from pathlib import Path
import sys

ROOT = Path(__file__).resolve().parent
if (ROOT / ".cad-deps").is_dir():
    sys.path.insert(0, str(ROOT / ".cad-deps"))
import manifold3d as m
import numpy as np
import trimesh


@dataclass(frozen=True)
class Dimensions:
    clearance: float = 0.35  # per mating side, NOT total diametral clearance
    wall: float = 2.4
    base_w: float = 120.0
    base_d: float = 106.0
    deck_z: float = 56.0
    head_w: float = 110.0
    head_d: float = 46.0
    head_h: float = 58.0
    pivot_z: float = 117.0
    oled_w: float = 27.5
    oled_h: float = 27.5
    oled_glass_w: float = 26.7
    oled_glass_h: float = 19.3
    oled_glass_depth: float = 2.3
    pcb_t: float = 1.6
    camera_w: float = 25.0
    camera_h: float = 24.0
    camera_aperture_d: float = 14.0
    camera_lens_offset_x: float = 0.0
    camera_lens_offset_z: float = 0.0
    oled_window_offset_z: float = 0.0
    servo_l: float = 23.2
    servo_w: float = 12.6
    servo_depth: float = 23.0  # below mounting-ear support plane
    servo_ear_l: float = 32.5
    servo_ear_t: float = 2.4
    servo_axis_offset: float = 5.7  # shaft offset from case longitudinal centre
    horn_l: float = 32.0   # supplied double arm horn; measure your particular horn
    horn_w: float = 6.0
    horn_t: float = 2.0
    horn_hub_d: float = 8.0
    horn_top_above_deck: float = 6.0
    latch_t: float = 1.2
    latch_deflection: float = 0.45
    pan_limit: float = 50.0
    tilt_limit: float = 25.0


# A small CSG wrapper keeps the OpenSCAD export identical to the evaluated mesh.
class Solid:
    def __init__(self, shape, scad):
        self.shape, self.scad = shape, scad

    def __add__(self, other):
        return Solid(self.shape + other.shape, f"union(){{{self.scad}{other.scad}}}")

    def __sub__(self, other):
        return Solid(self.shape - other.shape, f"difference(){{{self.scad}{other.scad}}}")

    def __xor__(self, other):
        return Solid(self.shape ^ other.shape, f"intersection(){{{self.scad}{other.scad}}}")

    def move(self, xyz):
        v = [float(n) for n in xyz]
        return Solid(self.shape.translate(v), f"translate({v}){{{self.scad}}}")

    def rotate(self, xyz):
        v = [float(n) for n in xyz]
        return Solid(self.shape.rotate(v), f"rotate({v}){{{self.scad}}}")

    def hull(self):
        return Solid(self.shape.hull(), f"hull(){{{self.scad}}}")


def box(x, y, z, w, d, h):
    assert min(w, d, h) > 0
    return Solid(m.Manifold.cube((w, d, h)), f"cube([{w},{d},{h}]);").move((x, y, z))


def cylinder(x, y, z, r, h, r2=None, n=48):
    top = r if r2 is None else r2
    return Solid(m.Manifold.cylinder(h, r, top, n),
                 f"cylinder(h={h},r1={r},r2={top},$fn={n});").move((x, y, z))


def union(items):
    items = list(items)
    if not items:
        return Solid(m.Manifold(), "")
    result = items[0]
    for item in items[1:]:
        result = result + item
    return result


def rounded(x, y, z, w, d, h, r=3):
    r = min(r, w / 2 - 0.01, d / 2 - 0.01)
    return union(cylinder(cx, cy, z, r, h, n=24)
                 for cx in (x + r, x + w - r)
                 for cy in (y + r, y + d - r)).hull()


def prism(points, height):
    return Solid(m.CrossSection([points]).extrude(height),
                 f"linear_extrude(height={height}) polygon({points});")


def along_x(x, y, z, r, length, r2=None):
    return cylinder(0, 0, 0, r, length, r2).rotate((0, 90, 0)).move((x, y, z))


def along_y(x, y, z, r, length):
    return cylinder(0, 0, 0, r, length).rotate((-90, 0, 0)).move((x, y, z))


def rail_y(x, y, z, length, width=5, height=3):
    # Trapezoidal section, slides along Y. Wider upper face resists lift.
    shape = prism([[-width / 2 + 1, 0], [width / 2 - 1, 0],
                   [width / 2, height], [-width / 2, height]], length)
    return shape.rotate((90, 0, 0)).move((x, y + length, z))


def horn_cut(d, z, height):
    return rounded(-d.horn_l / 2 - d.clearance, -d.horn_w / 2 - d.clearance,
                   z, d.horn_l + 2*d.clearance, d.horn_w + 2*d.clearance,
                   height, 1.5) + cylinder(0, 0, z, d.horn_hub_d/2+d.clearance, height)


@dataclass
class Part:
    name: str
    solid: Solid
    color: str
    explode: tuple
    print_rotation: tuple = (0, 0, 0)
    quantity: int = 1
    note: str = ""
    group: str = "fixed"


def spring_key(d, width=8.0, length=24.0):
    """Two 1.2mm planar beams; bidirectional ramps permit deliberate pull release.

    The rigid handle bears against the receiver. The key's shank takes shear;
    its small detents only prevent migration. Print flat, never scaled in slicer.
    """
    t = d.latch_t
    key = rounded(-7, -3, 0, 14, 5, 2.4, 1.5)
    key += box(-width/2, 0, 0, t, length-1.5, 2.4)
    key += box(width/2-t, 0, 0, t, length-1.5, 2.4)
    for sign in (-1, 1):
        x = sign*width/2
        pts = [[x-sign*(t+0.05), length-6], [x, length-6],
               [x+sign*d.latch_deflection, length-3.4],
               [x, length-1.0], [x-sign*(t+0.05), length-1.0]]
        if sign < 0:
            pts.reverse()
        key += prism(pts, 2.4)
        key += cylinder(sign*(width/2-t/2), 1, 0, t/2+0.3, 2.4, n=20)
    return key


def make_parts(d):
    c, w, H = d.clearance, d.wall, d.deck_z
    parts = []
    add = parts.append
    ivory, sage, dark, orange = "#e7e4da", "#78938d", "#263c43", "#e4a052"

    # 01 — rounded base, real hollow interior, two independent connector openings.
    base = rounded(-60, -53, 0, 120, 106, H, 14)
    base -= rounded(-60+w, -53+w, 3, 120-2*w, 106-2*w, H+1, 11.6)
    base -= rounded(-50, 46, 3, 100, 12, 33, 2)  # rear drawer entrance
    base -= box(-56.5, 39, 49.2, 113, 20, 9)  # rear entry for top deck
    base -= box(55, -32, 8, 12, 65, 27)  # USB / Ethernet insertion envelope
    base -= box(-45, -58, 8, 76, 12, 17)  # USB-C / HDMI / audio insertion envelope
    for x in (-42, -30, -18, -6, 6, 18, 30, 42):
        base -= rounded(x-2, -32, -1, 4, 66, 5, 1.8)
    for px in (-39,19):
        for py in (-24.5,24.5):
            base -= cylinder(px,py,-1,2.8,5,n=32)
    for side in (-1, 1):
        # Lower rails carry the drawer; upper rails carry the sliding deck.
        base += box(side*50.5-1.5, -43, 3, 3, 86, 4)
        base += box(-48 if side<0 else 45,-38,2.9,3,78,1.1)
        base += box(side*52.5-5.2, -40, 49.6, 10.4, 80, 2.8)
        base += rail_y(side*51, -39, 52, 78, 4.8, 2.5)
        # Tie rails to side wall without closing the connector openings.
        for y in (-39, 37):
            base += box(-58 if side<0 else 49, y, 3, 9, 6, 7)
            base += box(-58 if side<0 else 51, y, 49.6, 7, 6, 2.8)
        # Rear drawer-key receiver and deck-key receiver.
        base += box(-60 if side<0 else 49, 33, 6, 11, 12, 8)
        base -= box(-61 if side<0 else 40, 35.2, 8.2, 21, 8.6, 3.1)
        base += box(-60 if side<0 else 56.35, -36, 48.4, 3.65, 12, 7.6)
        base -= box(-61 if side<0 else 40, -33.8, 51.0, 21, 8.6, 3.1)
    # Side cooling slots stay outside the electrical connector cutouts.
    for y in (-30, -18, -6, 6, 18, 30):
        base -= box(-62, y-2, 20, 7, 4, 19)
    add(Part("01_base_shell", base, sage, (0, 0, -25), note="Floor down; supports only under upper rail roofs."))

    # 02 — PCB drawer: actual Pi mounting-hole pattern and removable snap pins.
    tray = rounded(-48.6, -42, 4, 97.2, 89, 2.4, 4)
    tray -= rounded(-34, -22, 3, 66, 44, 5, 5)
    tray += rounded(-49, 47, 3.5, 98, 4.2, 31.5, 2)
    tray -= rounded(-16, 46, 12, 32, 7, 12, 3)  # accessible pull and ventilation
    for side in (-1, 1):
        tray += box(-48.6 if side<0 else 41, 33, 6, 7.6, 12, 8)
        tray -= box(-61 if side<0 else 40, 35.2, 8.2, 21, 8.6, 3.1)
    # Pi4 holes are NOT centred along the 85mm dimension: 3.5 and61.5mm from left.
    for px in (-39,19):
        for py in (-24.5,24.5):
            tray += cylinder(px,py,6.2,3.6,2.8)
            tray -= cylinder(px,py,3,1.3,9,n=32)
    add(Part("02_electronics_drawer", tray, dark, (0, 65, -10),
             note="Floor down. Drop Pi onto four seats; retain through its mounting holes with four printed pins."))

    # 03 — removable top deck with servo ear seats and real body/wire apertures.
    deck = rounded(-56, -43, H-3.2, 112, 86, 3.2, 7)
    for side in (-1, 1):
        deck -= rail_y(side*51, -44, 52-c, 89, 4.8+2*c, 2.5+2*c)
        deck += box(-46.95 if side<0 else 40, -36, 49.5, 6.95, 12, 5.8)
        deck -= box(-61 if side<0 else 37, -33.8, 51.0, 24, 8.6, 3.1)
    # Case's long axis is X, output shaft deliberately offset from case centre.
    sx = d.servo_axis_offset
    deck -= rounded(sx-d.servo_l/2-c, -d.servo_w/2-c, H-5,
                    d.servo_l+2*c, d.servo_w+2*c, 10, 0.8)
    # Ear seats are recessed into the deck. Body can be installed from above.
    deck -= box(sx-d.servo_ear_l/2-c, -d.servo_w/2-c, H-2.4,
                d.servo_ear_l+2*c, d.servo_w+2*c, 5)
    # Bearing pedestal is separate from servo load path. Shaft/horn stays at centre.
    pedestal = cylinder(0, 0, H, 25, 4.1) - cylinder(0, 0, H-1, 17.35, 6.1)
    # Gaps give the removable servo gate access to the mounting ears.
    pedestal -= box(-27, -8, H-1, 54, 16, 7)
    deck += pedestal
    for x in (-32, 32):
        deck += box(x-4, -31, H-0.2, 8, 64, 5.5)
        deck += rail_y(x, -30, H+5, 62, 6, 2.6)
    # Keeper-key blocks accept keys from the rear. These carry no servo torque.
    for x in (-28, 28):
        deck += box(x-6, 33.35, H, 12, 9.65, 10.4)
        deck -= box(x-4.3, 22, H+6.3, 8.6, 24, 3.1)
    deck -= rounded(-15, 33, H-5, 30, 7, 11, 2)  # open rear cable route, away from shaft
    for x in (-44, 42):
        for y in (-22, -10, 2, 14):
            deck -= rounded(x-2, y-3, H-5, 4, 6, 10, 1.5)
    add(Part("03_sliding_top_deck", deck, ivory, (0, -55, 12),
             note="Underside down; localized supports beneath bearing bridges and dovetail overhangs."))

    # Pan servo ear gate slides over the recessed ears. Slot permits shaft/boss.
    gate = rounded(sx-20, -7.5, H+0.1, 40, 15, 1.2, 1.0)
    gate -= rounded(sx-d.servo_l/2-0.3, -d.servo_w/2-0.3, H-1,
                    d.servo_l+0.6, d.servo_w+0.6, 5, 1)
    # Gate is trapped axially by the pedestal and yoke when assembled.
    add(Part("04_pan_servo_gate", gate, orange, (0, -35, 27),
             note="Flat. Fit ear thickness first; trapped below the pan assembly."))

    # 05 — journal, flange, bridge, left pivot; detachable right tower joins at base.
    flange_bottom = H+4.4
    yoke = cylinder(0, 0, H+1.65, 17.0, 2.8)
    yoke += cylinder(0, 0, flange_bottom, 24, 3.2)
    yoke += cylinder(0, 0, H+7.5, 16.8, 3.5)
    yoke += rounded(-64, -18, H+11, 128, 36, 4, 6)
    # Removable stock horn slides into an underside pocket; never print splines.
    horn_top = H+d.horn_top_above_deck
    yoke -= horn_cut(d, H-2, horn_top+c-(H-2))
    yoke -= cylinder(0, 0, H-2, 6.1+c, 4.5)  # clear stationary gearbox boss
    # Left arm; X-axis extrusion of the Y/Z profile.
    profile = [[-18,H+14],[18,H+14],[18,d.pivot_z+2],
               [13,d.pivot_z+9],[-13,d.pivot_z+9],[-18,d.pivot_z+2]]
    left = prism(profile, 4).rotate((90,0,90)).move((-64,0,0))
    yoke += left
    yoke += along_x(-60.05, 0, d.pivot_z, 4, 6.5)
    yoke += along_x(-54.0, 0, d.pivot_z, 4, 0.8, 3.25)
    # Twin X-directed dovetails let the entire right tower retract from the head.
    for y in (-12, 12):
        yoke += rail_y(y, -64, H+14.8, 38, 6, 3.2).rotate((0,0,90))
    yoke += box(27, -18, H+14.8, 3, 36, 4.8)  # tower insertion hard stop
    yoke += box(48, 17.8, H+13, 12, 7, 9)
    yoke -= box(49.7, -20, H+17, 8.6, 47, 3.1)  # transverse tower locking key
    add(Part("05_pan_yoke", yoke, dark, (0, 0, 55),
             print_rotation=(0,90,0), group="pan",
             note="Left outer cheek on bed; support journal and crossbar as needed, keep bearing/pocket supports clean."))

    # 06 — front-inserted U keeper, with journal/flange running clearances.
    keeper = rounded(-37, -32, H+7.9, 74, 65, 2.5, 6)
    keeper -= cylinder(0, 0, H+7, 17.2+c, 5)
    keeper -= box(-17.2-c, 0, H+7, 34.4+2*c, 36, 5)
    for x in (-32,32):
        keeper += box(x-4.5,-31,H+5.65,9,50.5,2.45)
    for x in (-32, 32):
        keeper -= rail_y(x, -34, H+5-c, 70, 6+2*c, 2.6+2*c)
    for x in (-28, 28):
        keeper += box(x-6, 20, H+7.6, 12, 3, 2.8)
        keeper -= box(x-4.3, 18, H+6.3, 8.6, 22, 3.1)
    add(Part("06_pan_bearing_keeper", keeper, orange, (0, -60, 33),
             note="Flat; no support in running bore. Slide from FRONT after seating yoke; keys enter from rear."))

    # 07 — right tower is the complete detachable tilt drive carriage.
    tower = rounded(30.4, -18, H+15.2, 34, 36, 7, 3)
    for y in (-12, 12):
        tower -= rail_y(y, -68, H+14.8-c, 43, 6+2*c, 3.2+2*c).rotate((0,0,90))
    tower -= box(29.9,17.45,H+14.5,30.45,9,8)
    tower -= box(49.7, -20, H+17, 8.6, 47, 3.1)
    profile = [[-18,H+20],[18,H+20],[22,d.pivot_z+10],
               [17,d.pivot_z+14],[-13,d.pivot_z+14],[-18,d.pivot_z+9]]
    tower += prism(profile, 4).rotate((90,0,90)).move((60,0,0))
    # Through opening in arm admits shaft boss, while face bears on servo ears.
    tower -= along_x(59,0,d.pivot_z,6.0,8)
    # External cradle; shaft points toward -X, servo body long direction +Y.
    scy = d.servo_axis_offset
    cradle = rounded(scy-d.servo_ear_l/2-3, d.pivot_z-d.servo_w/2-3,
                     0, d.servo_ear_l+6, d.servo_w+6, d.servo_depth+7, 3)
    cradle = cradle.rotate((90,0,90)).move((64,0,0))
    cradle -= box(63, scy-d.servo_l/2-c, d.pivot_z-d.servo_w/2-c,
                  d.servo_depth+10, d.servo_l+2*c, d.servo_w+2*c)
    # Slots for factory mounting ears, and a rear wire exit.
    cradle -= box(63.9, scy-d.servo_ear_l/2-c, d.pivot_z-d.servo_w/2-c,
                  d.servo_depth+9, d.servo_ear_l+2*c, d.servo_w+2*c)
    cradle -= box(79, scy-5, d.pivot_z-12, 20, 10, 10)
    # Open outboard end for insertion; cap later captures rear of servo body.
    tower += cradle
    tower -= box(87.0, scy-d.servo_ear_l/2-1.5, d.pivot_z-d.servo_w/2-1.7,
                 3.1, d.servo_ear_l+3, d.servo_w+12)
    for side in (-1,1):
        edge=scy+side*(d.servo_ear_l/2+1.15)
        tower -= box(86.9,edge-0.7,d.pivot_z+0.7,3.3,1.4,2.6)
    add(Part("07_removable_tilt_tower", tower, sage, (65,0,45),
             print_rotation=(0,90,0), group="pan",
             note="Outer cheek down; selective supports in cradle. Install servo before sliding tower inward."))

    # Slide a broad gate across the back of tilt servo; it only bears on case edges.
    tilt_gate = rounded(87.35, scy-d.servo_ear_l/2-1.15, d.pivot_z-d.servo_w/2-1.35,
                        2.4, d.servo_ear_l+2.3, d.servo_w+2.7, 0.6)
    tilt_gate -= box(87, scy-5, d.pivot_z-3.5, 5, 10, 7)
    tilt_gate += box(87.35, scy-4, d.pivot_z+d.servo_w/2+1, 2.4, 8, 5)
    for side in (-1,1):
        edge=scy+side*(d.servo_ear_l/2+1.15)
        slit=edge-side*1.55
        tilt_gate -= box(87,slit-0.3,d.pivot_z-4.5,4,0.6,14)
        pts=[[edge-side*1.25,d.pivot_z],[edge,d.pivot_z],
             [edge+side*0.55,d.pivot_z+2],[edge,d.pivot_z+4],
             [edge-side*1.25,d.pivot_z+4]]
        if side<0:pts.reverse()
        tilt_gate += prism(pts,2.4).rotate((90,0,90)).move((87.35,0,0))
    add(Part("08_tilt_servo_gate", tilt_gate, orange, (88,0,45),
             print_rotation=(0,90,0), group="pan", note="Flat on broad face. Remove gate before removing servo."))

    # 09 — face shell. Rounded outline extruded front-to-back in Y.
    P = d.pivot_z
    outer = rounded(-55, P-29, 0, 110, 58, 39, 11).rotate((90,0,0)).move((0,16,0))
    # Inner shape starts behind a 2.4mm front face; rear remains open.
    inner = rounded(-55+w, P-29+w, 0, 110-2*w,58-2*w,40,8.6).rotate((90,0,0)).move((0,19.4,0))
    head = outer - inner
    # Three actual apertures normal to front face: the camera isn't a Z-axis hole.
    for x in (-32, 32):
        eye = rounded(x-12.4, P-7.4+d.oled_window_offset_z, 0, 24.8,14.8,8,3).rotate((90,0,0)).move((0,-18,0))
        head -= eye
    head -= along_y(d.camera_lens_offset_x,-27,P+d.camera_lens_offset_z,d.camera_aperture_d/2,12)
    # Dedicated board pockets, along Y. Boards drop from rear; over-rails retain edges.
    # Bare board fronts rest at y=-17.2; components face the bezel.
    for cx,bw,bh in [(-32,d.oled_w,d.oled_h),(32,d.oled_w,d.oled_h),(0,d.camera_w,d.camera_h)]:
        for sx in (-1,1):
            x = cx + sx*(bw/2+c)
            railx = x-1.8 if sx<0 else x
            head += box(railx,-21.0,P-bh/2-1.8,1.8,8.4,bh+3.6)
        # Edge shelves avoid pressure on chips. Back comb supplies retention.
        head += box(cx-bw/2-1.8,-21.0,P-bh/2-1.8,bw+3.6,8.4,1.8)
        for side in (-1,1):
            for zz in (P-bh/2,P+bh/2-2):
                head += box(cx+side*(bw/2-1.0)-0.6,-21.0,zz,1.2,3.5,2)
    # Head side journals: left is a plain bearing; right is a captive horn pocket.
    head += along_x(-59.65,0,P,11,7.05)
    head -= along_x(-61,0,P,4+c,14)
    head += along_x(52.6,0,P,18.2,7.05)
    # Map the Z-directed horn pocket onto X, long arm along Y.
    tilt_hole = horn_cut(d,0,4).rotate((90,0,90)).move((56.9,0,P))
    head -= tilt_hole
    head -= along_x(57,0,P,d.horn_hub_d/2+c,5)
    # Sliding rear cover rails run downwards along Z on both side walls.
    for x in (-48,48):
        # T runners retain the cover against peeling and slide open along Z.
        # Connect inner cover runners to shell through short end bridges.
        head += box(x-0.8,9.0,P-24,1.6,5.5,48)
        head += box(x-1.8,14.35,P-24,3.6,3.15,48)
        head += box(-54 if x<0 else 46.2,9.0,P-24,7.8,2.45,48)
        head += box(-54 if x<0 else 46.2,12.7,P-24,7.8,3.0,3)
        head -= box(x-3.85,11.45,P+20.8,7.7,12,15)  # open rail run-in at crown
    head -= box(-13,6,P-32,26,15,7)  # real ribbon opening in underside
    # Cover cross-key receiver at crown, outside electronics envelope.
    head += box(-6,9,P+22,12,9,5)
    head -= box(-4.3,7,P+23,8.6,14,3.1)
    add(Part("09_head_face_shell", head, ivory, (0,-45,85),
             print_rotation=(90,0,0), group="head",
             note="Face on bed. Support side journal bosses and rail overhangs only; protect the eye windows."))

    # 10 — rear cowl slides down onto cheek ledges; a pull key prevents upward removal.
    rear = rounded(-55,P-29,0,110,58,6.65,11).rotate((90,0,0)).move((0,23,0))
    rear -= rounded(-52.6,P-26.6,0,105.2,53.2,7,8.6).rotate((90,0,0)).move((0,20.6,0))
    for x in (-48,48):
        rear += box(x-3.5,11.8,P-20.5,7,9.2,41)
        rear -= box(x-1.8-c,14.0,P-35,3.6+2*c,3.9,75)
        rear -= box(x-0.8-c,11.1,P-35,1.6+2*c,3.0,75)
        rear -= box(x-4.15,11.1,P-35,8.3,6.8,14.2)  # lower rim passes rail end stop
    rear -= box(-13,9,P-32,26,18,7)
    for x in (-34,-20,20,34):
        rear -= box(x-2,18,P-16,4,9,32)
    rear -= box(-4.3,7,P+23,8.6,20,3.1)
    rear -= box(-6.35,8.6,P+21.65,12.7,9.8,5.7)
    rear -= along_x(51.5,0,P,18.2+c,11)
    rear -= box(51.5,-18.55,P-32,11,37.1,32)
    for x in (-43,43):
        rear -= box(x-1.35,15.9,P-32,2.7,4.65,16.35)
    add(Part("10_sliding_rear_cowl", rear, sage, (0,58,100),
             print_rotation=(-90,0,0), group="head",
             note="Rear face down; support inside rail roofs, leave ventilation/cable openings clear."))

    # 11 — removable PCB comb: edge bars overlap PCB backs, held by cowl pressure stops.
    comb = box(-45.9,-12.25,P-18,91.8,2.0,2.0)
    for cx,bw,bh in [(-32,d.oled_w,d.oled_h),(0,d.camera_w,d.camera_h),(32,d.oled_w,d.oled_h)]:
        for side in (-1,1):
            comb += box(cx+side*(bw/2-0.5)-0.65,-15.55,P-bh/2+0.35,1.3,4.15,bh+1.65)
            comb += box(cx+side*(bw/2-0.5)-0.65,-12.25,P-18,1.3,2.0,18-bh/2+2)
            comb += box(cx+side*(bw/2-0.5)-0.65,-17.85,P+bh/2+0.35,1.3,6.45,1.3)
    # Long spacers terminate against rear cowl interior; one part captures all three boards.
    for x in (-43,43):
        comb += box(x-1,-12.25,P-18,2,32.5,2)
    add(Part("11_display_retaining_comb", comb, orange, (0,22,83),
             print_rotation=(90,0,0), group="head",
             note="Broad comb plane down. Edge contacts only; verify PCB component clearance before fitting."))

    # 12 — universal flat locking key, with deliberately separate, replaceable flexures.
    add(Part("12_pull_release_key", spring_key(d), orange, (75,40,0),
             quantity=8, note="Print flat, 100% infill, seam away from beam roots. Fit coupon first.",group="hardware"))

    # 13 — removable board pins engage the official mounting holes, without screws.
    pcb_pin = cylinder(0,0,0,2.5,1.6,n=32)+cylinder(0,0,1.5,1.15,7.9,n=32)
    pcb_pin += cylinder(0,0,7.7,1.15,0.9,1.45,n=32)
    pcb_pin += cylinder(0,0,8.6,1.45,0.8,1.05,n=32)
    pcb_pin -= box(-0.4,-3,2.4,0.8,6,8)
    add(Part("13_pcb_snap_pin",pcb_pin,orange,(75,15,0),print_rotation=(90,0,0),quantity=4,
             note="Print on side with brim; clean support from shaft. Test pin and seat coupon before board installation.",group="hardware"))
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

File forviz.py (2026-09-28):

"""FORVIZ - Autonomous Face Tracking Robot with Groq Voice Assistant.

Features:
  - Real-time YuNet AI face detection & pan/tilt servo tracking (15 FPS).
  - Dual/Single SSD1306 OLED animated eyes with gaze tracking and expressions.
  - Voice Assistant powered by Groq API (Whisper STT + Llama 3.3 LLM + TTS).
  - Defaults to --mirror-eye mode for standard same-bus dual OLED setups.
  - Works with standard headsets/headphones plugged into Raspberry Pi.

Run:
  python3 forviz.py
"""
import argparse
import audioop
import base64
import io
import json
import math
import os
from pathlib import Path
import queue
import shutil
import subprocess
import sys
import tempfile
import threading
import time
import urllib.error
import urllib.parse
import urllib.request
import wave

import cv2
from servos import PanTiltTracker
from oled_face import DEFAULT_OLED_ROTATION, OLEDDisplayController, RobotEyesRenderer

YUNET_MODEL_PATH = str(Path(__file__).resolve().with_name('face_detection_yunet_2023mar.onnx'))

try:
    from picamera2 import Picamera2
    PICAM2_AVAILABLE = True
except ImportError:
    PICAM2_AVAILABLE = False

# Audio libraries (optional imports with graceful fallbacks)
try:
    import pyaudio
    PYAUDIO_AVAILABLE = True
except ImportError:
    PYAUDIO_AVAILABLE = False

try:
    import sounddevice as sd
    import numpy as np
    SOUNDDEVICE_AVAILABLE = True
except ImportError:
    SOUNDDEVICE_AVAILABLE = False

try:
    import pygame
    PYGAME_AVAILABLE = True
except ImportError:
    PYGAME_AVAILABLE = False

try:
    from gtts import gTTS
    GTTS_AVAILABLE = True
except ImportError:
    GTTS_AVAILABLE = False

try:
    from groq import Groq
    GROQ_SDK_AVAILABLE = True
except ImportError:
    GROQ_SDK_AVAILABLE = False


# ---------------------------------------------------------------------------
# 1. CAMERA STREAM (Picamera2 / OpenCV fallback)
# ---------------------------------------------------------------------------
class PiCameraStream:
    """Handles camera capture using Picamera2 or OpenCV fallback."""
    def __init__(self, width=320, height=240, fps=15, hflip=True, vflip=False):
        self.width = width
        self.height = height
        self.fps = fps
        self.hflip = hflip
        self.vflip = vflip
        self.use_picam2 = PICAM2_AVAILABLE
        self.picam2 = None
        self.cap = None

        if self.use_picam2:
            try:
                print("[CAM] Initializing Raspberry Pi Camera via Picamera2...")
                self.picam2 = Picamera2()
                frame_us = round(1_000_000 / fps)
                config = self.picam2.create_preview_configuration(
                    main={"size": (width, height), "format": "RGB888"},
                    controls={"FrameDurationLimits": (frame_us, frame_us)},
                    queue=False,
                )
                self.picam2.configure(config)
                self.picam2.start()
                time.sleep(1.0)
                print("[CAM] Picamera2 started successfully.")
            except Exception as e:
                print(f"[CAM WARNING] Picamera2 failed ({e}). Falling back to cv2.VideoCapture...")
                if self.picam2 is not None:
                    self.picam2.close()
                    self.picam2 = None
                self.use_picam2 = False

        if not self.use_picam2:
            print("[CAM] Opening camera via OpenCV VideoCapture(0)...")
            self.cap = cv2.VideoCapture(0)
            self.cap.set(cv2.CAP_PROP_FRAME_WIDTH, width)
            self.cap.set(cv2.CAP_PROP_FRAME_HEIGHT, height)
            self.cap.set(cv2.CAP_PROP_FPS, fps)
            self.cap.set(cv2.CAP_PROP_BUFFERSIZE, 1)
            if not self.cap.isOpened():
                self.cap.release()
                raise RuntimeError("Failed to open camera! Check CSI ribbon cable or run 'rpicam-hello'.")

    def read(self):
        if self.use_picam2:
            frame = self.picam2.capture_array()
            ret = True
        else:
            ret, frame = self.cap.read()
        if ret and frame is not None:
            hflip = getattr(self, 'hflip', False)
            vflip = getattr(self, 'vflip', False)
            if hflip and vflip:
                frame = cv2.flip(frame, -1)
            elif hflip:
                frame = cv2.flip(frame, 1)
            elif vflip:
                frame = cv2.flip(frame, 0)
        return ret, frame

    def release(self):
        if self.use_picam2 and self.picam2 is not None:
            try:
                self.picam2.stop()
            finally:
                self.picam2.close()
        elif self.cap is not None:
            self.cap.release()


# ---------------------------------------------------------------------------
# 2. YUNET FACE DETECTOR (ONNX CPU INFERENCE)
# ---------------------------------------------------------------------------
class FaceDetectorYuNet:
    """Ultra-lightweight (232KB) Face Detector for Raspberry Pi 4 CPU."""
    def __init__(self, model_path=YUNET_MODEL_PATH, conf_threshold=0.6, nms_threshold=0.3,
                 max_input_size=320):
        if max_input_size < 64:
            raise ValueError('Detection input size must be at least 64 pixels')
        self.max_input_size = max_input_size
        self._input_size = None
        if not os.path.exists(model_path):
            raise FileNotFoundError(f"Model file '{model_path}' not found! Run setup_pi.sh to download it.")

        self.detector = cv2.FaceDetectorYN.create(
            model=str(model_path),
            config="",
            input_size=(320, 320),
            score_threshold=conf_threshold,
            nms_threshold=nms_threshold,
            top_k=2000,
            backend_id=cv2.dnn.DNN_BACKEND_OPENCV,
            target_id=cv2.dnn.DNN_TARGET_CPU
        )

    def detect(self, frame):
        h, w = frame.shape[:2]
        t0 = time.perf_counter()
        scale = min(1.0, self.max_input_size / max(w, h))
        dw, dh = max(1, round(w * scale)), max(1, round(h * scale))
        small = frame if (dw, dh) == (w, h) else cv2.resize(frame, (dw, dh), interpolation=cv2.INTER_AREA)
        if self._input_size != (dw, dh):
            self.detector.setInputSize((dw, dh))
            self._input_size = (dw, dh)
        _, faces = self.detector.detect(small)
        latency_ms = (time.perf_counter() - t0) * 1000

        results = []
        if faces is not None:
            for face in faces:
                sx, sy = w / dw, h / dh
                x, y, bw, bh = [int(round(float(v) * s)) for v, s in zip(face[0:4], (sx, sy, sx, sy))]
                conf = float(face[14])
                landmarks = [(int(round(float(face[i]) * sx)), int(round(float(face[i+1]) * sy)))
                             for i in range(4, 14, 2)]
                results.append({
                    "box": (x, y, bw, bh),
                    "confidence": conf,
                    "landmarks": landmarks
                })
        return results, latency_ms
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

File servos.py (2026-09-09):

"""Shared SG90 pan/tilt control. PWM detach releases holding torque, not power."""
import math
import time

try:
    import pigpio
    PIGPIO_AVAILABLE = True
except ImportError:
    PIGPIO_AVAILABLE = False

try:
    from gpiozero import AngularServo
    from gpiozero.pins.pigpio import PiGPIOFactory
    GPIOZERO_AVAILABLE = True
except ImportError:
    GPIOZERO_AVAILABLE = False


class PanTiltTracker:
    """Time-based bounded motion, with conservative V3 operating limits.

    max_speed_deg is a legacy degrees/frame argument, converted at 30 FPS.
    New callers should use max_speed_deg_per_sec. A 100 ms elapsed-time cap
    prevents large moves after an inference stall. Idle detach is opt-in:
    a loaded head may drop when PWM stops.
    """
    def __init__(self, pan_pin=12, tilt_pin=19,
                 pan_range=(40, 140), tilt_range=(65, 115),
                 pan_center=90, tilt_center=90,
                 max_speed_deg=None, idle_timeout_sec=None, *,
                 max_speed_deg_per_sec=36.0, scan_speed_deg_per_sec=18.0,
                 hardware=True, clock=None,
                 invert_pan=False, invert_tilt=False):
        self.pan_min, self.pan_max = self._validate_range(pan_range)
        self.tilt_min, self.tilt_max = self._validate_range(tilt_range)
        for center, low, high in ((pan_center, self.pan_min, self.pan_max),
                                  (tilt_center, self.tilt_min, self.tilt_max)):
            if not math.isfinite(center) or not low <= center <= high:
                raise ValueError('Servo center must be inside its configured range')
        if max_speed_deg is not None:
            max_speed_deg_per_sec = max_speed_deg * 30.0
        if (not math.isfinite(max_speed_deg_per_sec) or max_speed_deg_per_sec <= 0
                or not math.isfinite(scan_speed_deg_per_sec) or scan_speed_deg_per_sec <= 0):
            raise ValueError('Servo speeds must be finite and positive')
        if idle_timeout_sec is not None and (not math.isfinite(idle_timeout_sec) or idle_timeout_sec <= 0):
            raise ValueError('Idle detach timeout must be positive or None')
        self.pan_pin, self.tilt_pin = pan_pin, tilt_pin
        self.pan_center, self.tilt_center = float(pan_center), float(tilt_center)
        self.current_pan = self.target_pan = self.pan_center
        self.current_tilt = self.target_tilt = self.tilt_center
        self.max_speed_deg_per_sec = float(max_speed_deg_per_sec)
        self.scan_speed_deg_per_sec = min(float(scan_speed_deg_per_sec), self.max_speed_deg_per_sec)
        self.idle_timeout_sec = idle_timeout_sec
        self.min_us, self.max_us = 600, 2300
        self._clock = clock or time.monotonic
        self._last_update = self.last_move_time = self._clock()
        self.is_sleeping = self._closed = False
        self.scan_direction = 1
        self.invert_pan = invert_pan
        self.invert_tilt = invert_tilt
        self.backend = 'DUMMY'
        self.pi = self.pan_servo = self.tilt_servo = self._factory = None
        if hardware:
            self._connect()
        if self.backend == 'DUMMY':
            print('[SERVOS] Simulation mode: no physical GPIO output.')
        try:
            self._write_angles(self.current_pan, self.current_tilt)
        except Exception:
            self.close()
            raise
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

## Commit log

2026-09-04 feat: Add SG90 pan-tilt servo controller and SSD1306 OLED animated eyes engine
2026-09-04 fix: make pi_tracker.py 100% self-contained and update setup_pi.sh dependencies
    [pi_tracker.py]
2026-09-05 fix(servos): Switch Pan to GPIO 12 (Pin 32), add hardware DMA timing, slew rate limiting, and idle auto-rest to eliminate overheating and jitter
    [pi_tracker.py, servos.py, test_servos.py]
2026-09-05 fix(servos): Switch Tilt to GPIO 19 (Pin 35), add EMA coordinate smoothing to eliminate camera flutter jitter
    [pi_tracker.py, servos.py, test_servos.py]
2026-09-05 feat(3d-cad): Add 3D printable STL models and OpenSCAD parametric design for robot head, gimbal bracket, and base
    [neck_tilt_bracket.stl, robot_base_stand.stl, robot_body.scad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]
2026-09-05 refactor(3d-cad): Complete V2 redesign of robot chassis with thin-walled snap-fit head, functional U-gimbal neck, wire routing conduits, and Pi 4 torso enclosure
    [head_front_faceplate.stl, head_rear_cowl.stl, pan_tilt_gimbal.stl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]
2026-09-09 feat: Add center_servos.py calibration script to zero/center Pan and Tilt servos before mechanical assembly
2026-09-09 feat(oled): Add CLI rotation arguments (--oled-rotate, --oled1-rotate, --oled2-rotate) for flipped/rotated glued displays
    [oled_face.py, pi_tracker.py, test_oled.py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]
2026-09-09 docs: Add high-resolution Raspberry Pi 4 wiring pinout infographic image
2026-09-09 fix(i2c): Add i2c_gpio_delay_us=5 to enable_dual_oled.sh to eliminate software I2C signal glitching
2026-09-09 feat(oled): Add --mirror-eye mode for zero-solder dual screens on Pin 3 & 5
2026-09-09 feat(tracking): Add --invert-tilt, --invert-pan, and --invert-y flags for natural head/eye motion
    [pi_tracker.py, servos.py, test_runtime.py]
2026-09-09 fix(gaze): Make eye vertical gaze naturally look UP when face is UP at 0 deg rotation
    [pi_tracker.py, test_runtime.py]
2026-09-09 perf(servos): Invert default Pan/Tilt directions for natural tracking, boost speed to 90 deg/s and improve motion smoothing
    [pi_tracker.py, servos.py]
2026-09-09 perf(tracking): Add adaptive sensor noise filter and increase max servo speed to 120 deg/s
    [pi_tracker.py]
2026-09-15 fix(camera): Enable horizontal mirror flip by default so monitor view and tracking align with left/right motion
    [pi_tracker.py, test_performance.py]
2026-09-17 change default parameter for servo speed and eye fixed
    [pi_tracker.py, test_runtime.py]
